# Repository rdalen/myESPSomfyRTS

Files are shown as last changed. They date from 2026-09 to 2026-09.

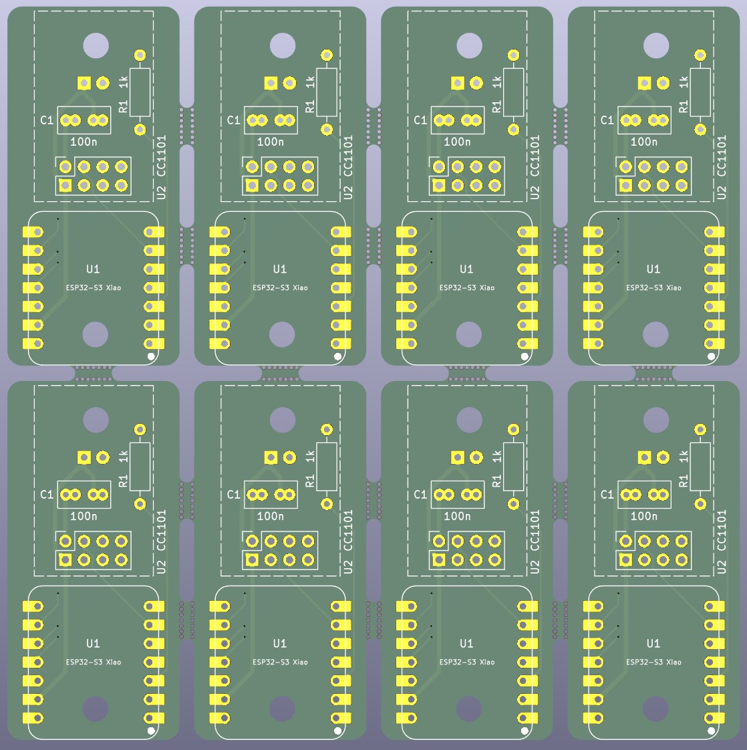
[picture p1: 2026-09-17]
KiCad/ESPSomfyRTS-Panel/ESPSomfyRTS-Panel.jpg

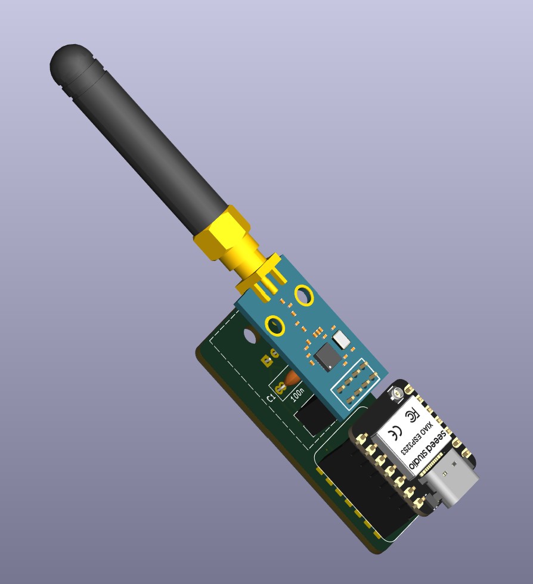
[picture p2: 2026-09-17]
KiCad/ESPSomfyRTS-PcbLayout.jpg

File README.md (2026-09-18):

# myESPSomfyRTS

A DIY Somfy RTS controller for my SunRain Awning/Shade, based on the open-source [ESPSomfyRTS](https://github.com/rstrouse/ESPSomfy-RTS) project.

The controller uses an ESP32 together with a CC1101 433 MHz RF transceiver and integrates with my Home Assistant and Node-RED setup.


<p align="center"><i>Architecture diagram</i></p>

## How It Works

- **Hardware:** ESP32 microcontroller paired with a CC1101 radio transceiver module.
- **Communication:** Connects to my home Wi-Fi network and sends 433 MHz radio signals compatible with the Somfy RTS (Radio Technology Somfy) protocol.
- **Local Operation:** ESPSomfyRTS provides a built-in web interface for controlling the shade directly from a phone or computer.
- **Smart Home Integration:** The controller integrates with Home Assistant and Node-RED for automation and monitoring.
- **Position Tracking:** Tracks the shade position independently of the physical Somfy remote.

For the firmware, general wiring information and ESPSomfyRTS documentation, see the official [ESPSomfyRTS project](https://github.com/rstrouse/ESPSomfy-RTS).

An instruction video is available on [YouTube](https://www.youtube.com/watch?v=1acVJ0xWJgs).

---

## Repository Contents

This repository contains the files specific to my implementation:

- 📁 **[KiCad](./KiCad)** — Schematic and PCB design files
- 📁 **[nodeRed](./nodeRed)** — Node-RED flows used for control, monitoring and automation

The ESP32 firmware itself is based on the [ESPSomfyRTS](https://github.com/rstrouse/ESPSomfy-RTS) project.

---

## CC1101 433 MHz RF Transceiver

CC1101 RF transceiver

E07-M1101D-SMA module

My version of the CC1101-based module (E07-M1101D-SMA) exposes only a single GDO line, while ESPSomfyRTS is often configured with separate RX and TX signal pins.

By assigning both RX and TX to the same GPIO, ESPSomfyRTS can use the single GDO line for both receiving and transmitting.

The GPIO configuration with the Seeed Studio XIAO ESP32-S3 is:

- **RX Pin = GPIO3**
- **TX Pin = GPIO3** ← same GPIO as RX

### ESP32-S3 XIAO

Pin connections between the CC1101 module and the XIAO ESP32-S3:

XIAO ESP32-S3 pinout

| CC1101 Pin | Description | ESP Signal | ESP Pin |
| --- | --- | --- | --- |
| 1 | GND | GND | 13 |
| 2 | VCC | 3V3 | 12 |
| 3 | GDO0 - RX/TX | GPIO 03 | 3 |
| 4 | CSN | GPIO 06 | 6 |
| 5 | SCK | GPIO 07 | 9 |
| 6 | MOSI | GPIO 09 | 11 |
| 7 | MISO | GPIO 08 | 10 |
| 8 | Not connected | | |

Here is the corresponding ESPSomfyRTS radio configuration:

ESPSomfyRTS radio configuration

---

## Schematic & PCB

I designed a small custom PCB for the controller.

The complete KiCad project is available in the **[KiCad](./KiCad)** folder.

PCB

ESPSomfyRTS PCB layout



PCB



PCB

Before ordering, I panelized the PCB design so I have several boards available for experimenting with and sharing.



---

## Enclosure

Finally, I "Boxified" an enclosure for the controller using my [Boxify Parametric Electronics Enclosure Framework](https://cad.onshape.com/documents/2429cd535c2c818681c446f4/w/762b6c313c33766c159c34b3/e/4a0a0d23bcb24ef244694428).

See also my [Boxify Instructable](https://www.instructables.com/-Boxify-a-Parametric-Electronics-Enclosure-Framewo).

The enclosure was then 3D printed.

3D printed enclosure

Enclosure

---

## Controlling the SunRain Shade

The Somfy motor does not provide a motor-running feedback signal.

I therefore derive the motor-running state from a HomeWizard Energy Socket. The motor uses approximately 200 W while running, making it possible to detect whether the motor is active.



For controlling and monitoring the shade I created a Node-RED dashboard.

The complete Node-RED flow is available in the **[nodeRed](./nodeRed)** folder.

The dashboard allows me to:

- control the shade
- monitor whether the motor is responding
- track the shade position
- detect when the motor is running
- receive a warning when rain is predicted within 30 minutes

Node-RED dashboard

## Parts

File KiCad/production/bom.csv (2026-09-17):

Designator | Footprint | Quantity | Value | LCSC Part #
C1_8, C1_7, C1_6, C1_5, C1_4, C1_3, C1_2, C1 | C-Common-THT-P5.08mm | 8 | 100n
D1_8, D1_7, D1_6, D1_5, D1_4, D1_3, D1_2, D1 | LED-D3.0mm | 8 | LED
LOGO1_8, LOGO1_7, LOGO1_6, LOGO1_5, LOGO1_4, LOGO1_3, LOGO1_2, LOGO1 | LOGO-RvD-inverted-small | 8 | Logo-RvD
LOGO2_8, LOGO2_7, LOGO2_6, LOGO2_5, LOGO2_4, LOGO2_3, LOGO2_2, LOGO2 | LOGO-TechDen-inverted | 8 | Logo-TechDen
R1_8, R1_7, R1_6, R1_5, R1_4, R1_3, R1_2, R1 | R-Common-THT-P10.16mm | 8 | 1k
U1_8, U1_7, U1_6, U1_5, U1_4, U1_3, U1_2, U1 | MOD-ESP32-S3-XIAO-DIP | 8 | ESP32-S3 Xiao
U2_8, U2_7, U2_6, U2_5, U2_4, U2_3, U2_2, U2 | MOD-CC1101 | 8 | CC1101

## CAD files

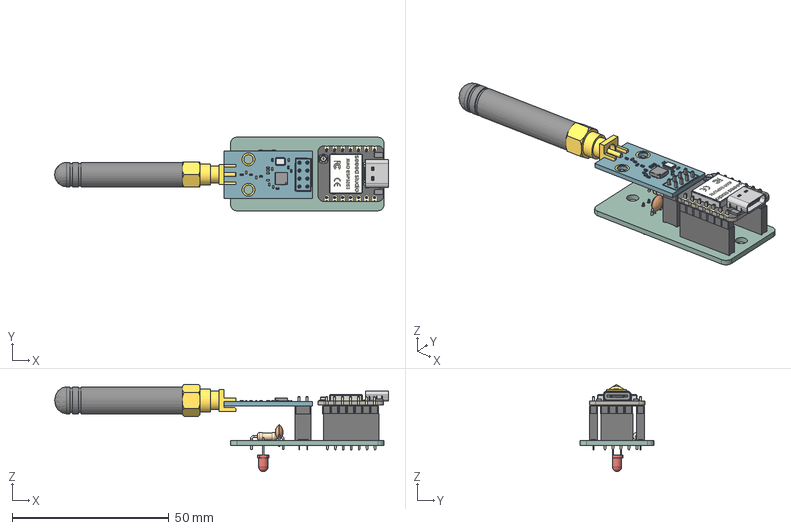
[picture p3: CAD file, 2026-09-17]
KiCad/ESPSomfy RTS.step
106.6 x 23.5 x 27.8 mm
R-Common-THT-P10.16mm
PinHeader_1x07_P2.54mm_Vertical x 2
BOSS-EXTRUDE14_8_
BOSS-EXTRUDE7_4_
BOSS-EXTRUDE7_3_
BOSS-EXTRUDE14_4_
BOSS-EXTRUDE14_2_
BOSS-EXTRUDE14_11_
BOSS-EXTRUDE7_7_
BOSS-EXTRUDE14_9_
BOSS-EXTRUDE14_3_
BOSS-EXTRUDE14_7_
MIRROR2
BOSS-EXTRUDE14_5_
BOSS-EXTRUDE14_12_
BOSS-EXTRUDE7_8_
BOSS-EXTRUDE7_1_
BOSS-EXTRUDE14_10_
BOSS-EXTRUDE7_9_
BOSS-EXTRUDE14_6_
BOSS-EXTRUDE14_1_
BOSS-EXTRUDE7_6_
BOSS-EXTRUDE7_2_
CUT-EXTRUDE5
BOSS-EXTRUDE7_5_
Shield
Pins x 2
U.FL-R-SMT-1_10_ v1
PinSocket_1x07_P2.54mm_Vertical x 2
C-Common-THT-P5.08mm
bits (16)
bits (16)001
bits (16)002
bits (15)
bits (15)001
bits (15)002
bits (14)
bits (14)001
bits (14)002
bits (13)
bits (13)001
bits (13)002
bits (12)
bits (12)001
bits (12)002
bits (11)
bits (11)001
bits (11)002
bits (10)
bits (10)001
bits (10)002
bits (9)
bits (9)001
bits (9)002
bits (8)
bits (8)001
bits (8)002
bits (7)
bits (7)001
bits (7)002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

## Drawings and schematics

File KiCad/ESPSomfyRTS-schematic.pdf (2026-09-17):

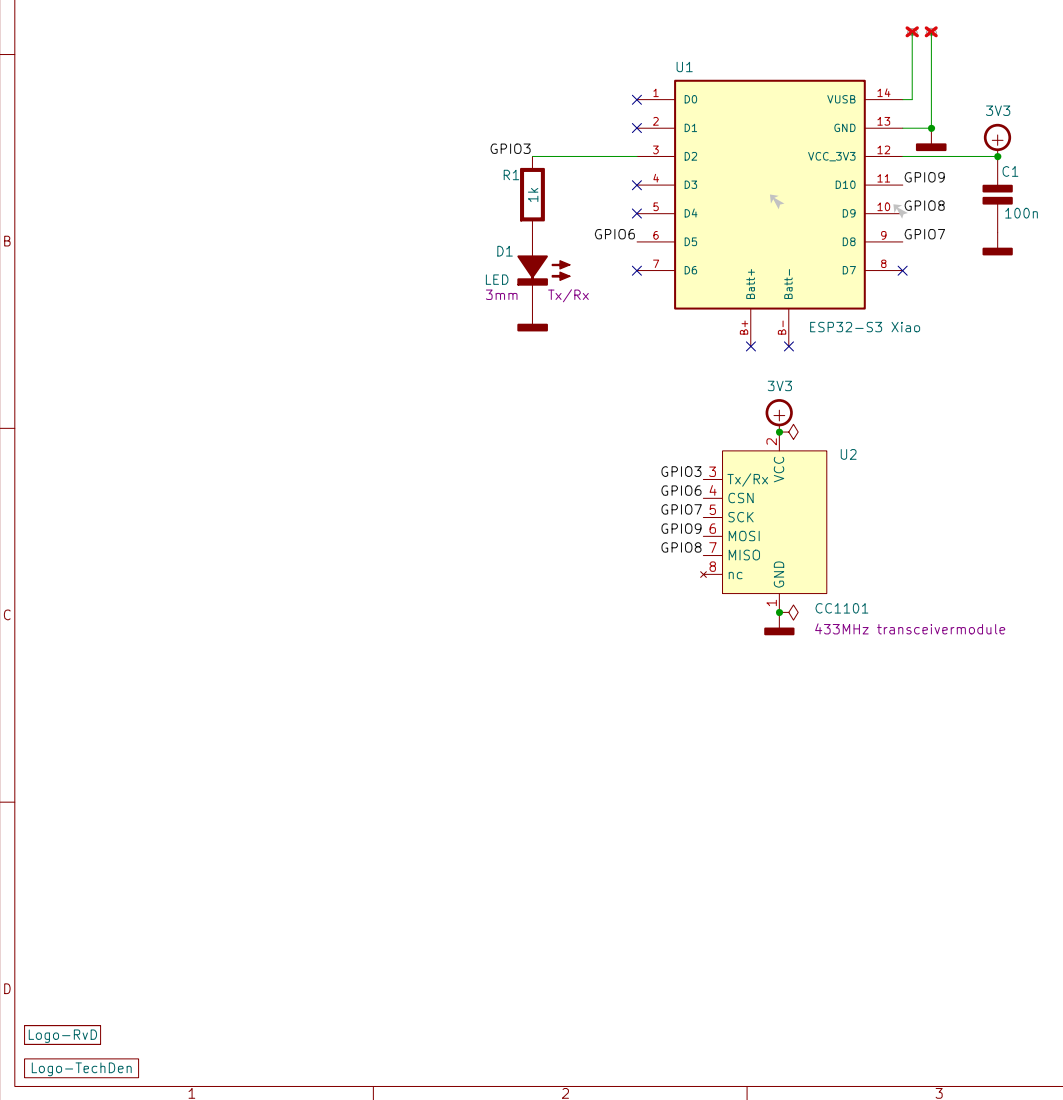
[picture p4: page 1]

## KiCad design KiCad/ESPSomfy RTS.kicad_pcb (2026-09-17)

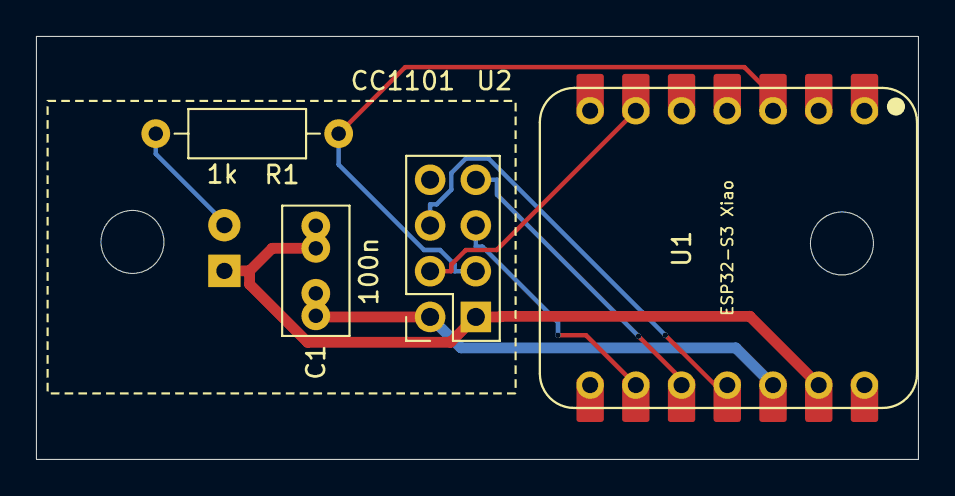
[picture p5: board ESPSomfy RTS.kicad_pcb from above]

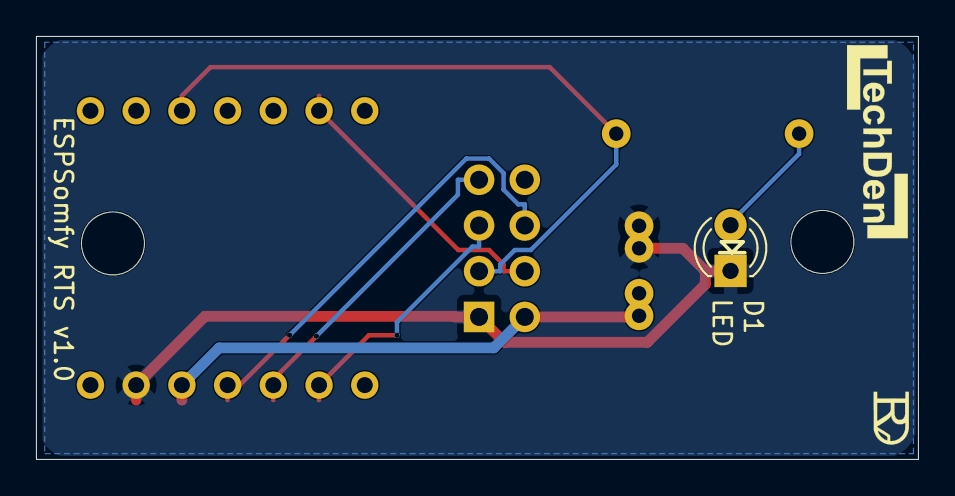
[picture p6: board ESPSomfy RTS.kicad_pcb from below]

Board: 2 copper layers, 49.0 x 23.5 mm, 7 parts (3 on the bottom side), 8 nets.

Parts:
C1: 100n; C-Common-THT-P5.08mm
D1: LED; LED-D3.0mm
Logo1: Logo-RvD; LOGO-RvD-inverted-small
Logo2: Logo-TechDen; LOGO-TechDen-inverted
R1: 1k; R-Common-THT-P10.16mm
U1: ESP32-S3 Xiao; MOD-ESP32-S3-XIAO-DIP
U2: CC1101; MOD-CC1101

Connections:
3V3: C1.1 (+), U1.12 (VCC_3V3), U2.2 (VCC)
/GPIO3: R1.1 (+), U1.3 (D2), U2.3 (Tx/Rx)
/GPIO6: U1.6 (D5), U2.4 (CSN)
/GPIO7: U1.9 (D8), U2.5 (SCK)
/GPIO8: U1.10 (D9), U2.7 (MISO)
/GPIO9: U1.11 (D10), U2.6 (MOSI)
unnamed: D1.2 (A+), R1.2 (-)
U-GND: C1.2 (-), D1.1 (K-), U1.13 (GND), U2.1 (GND)

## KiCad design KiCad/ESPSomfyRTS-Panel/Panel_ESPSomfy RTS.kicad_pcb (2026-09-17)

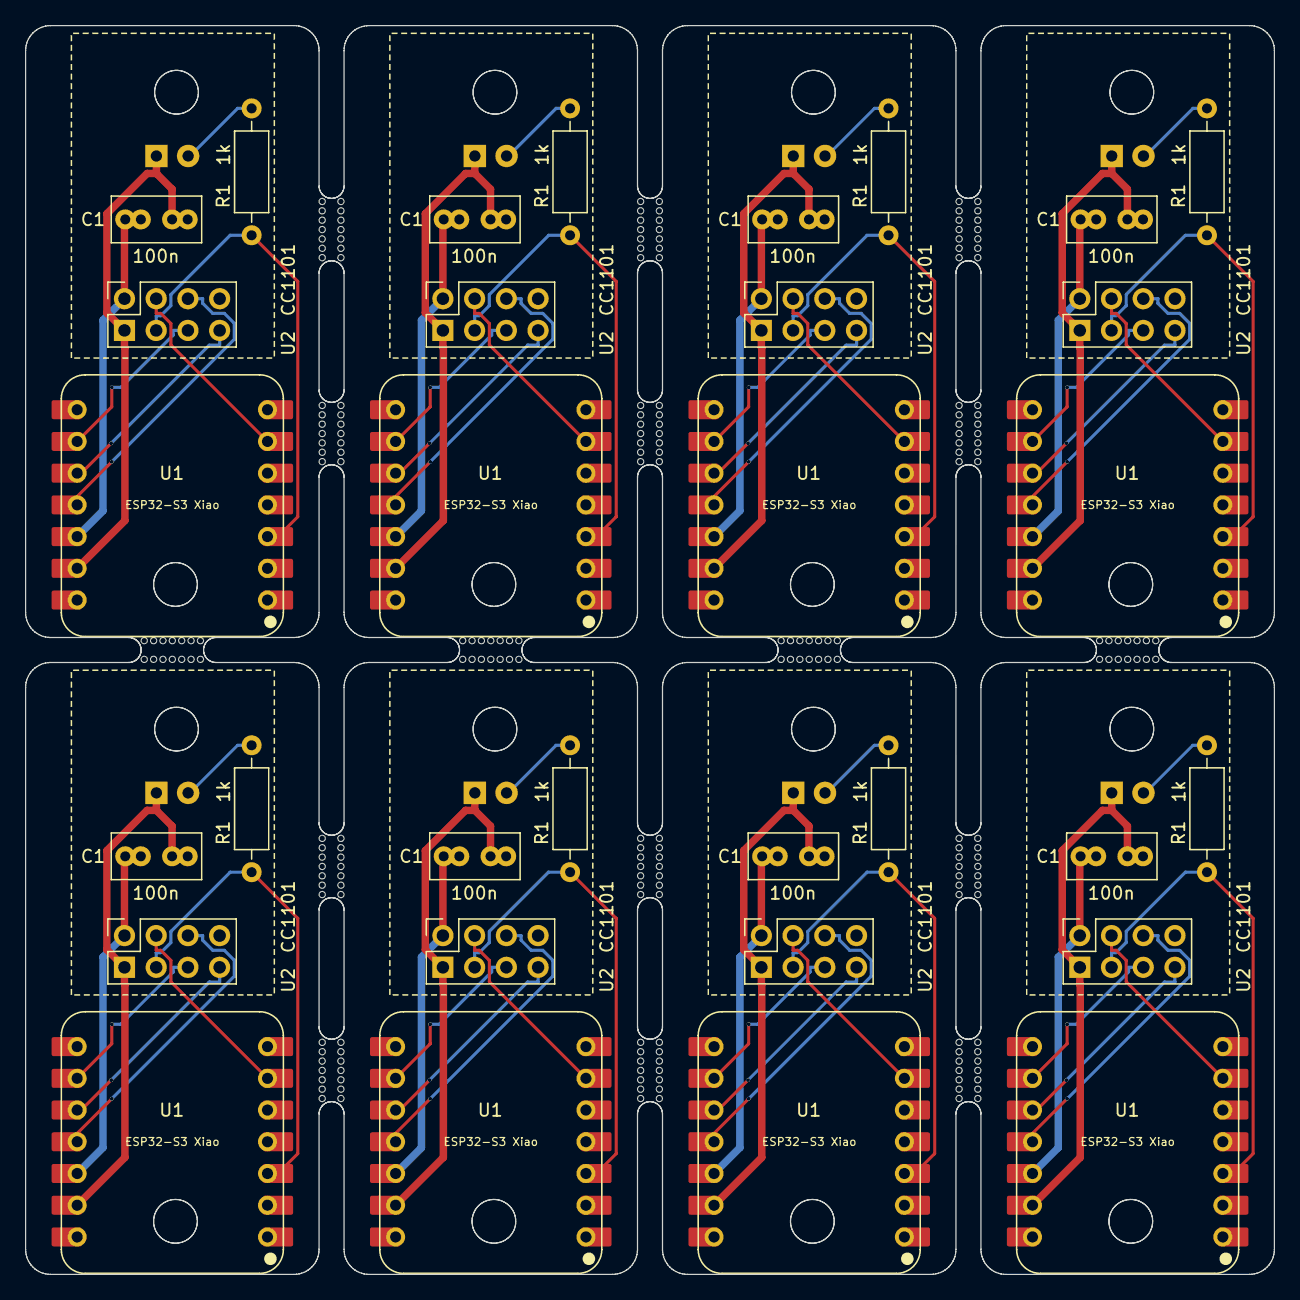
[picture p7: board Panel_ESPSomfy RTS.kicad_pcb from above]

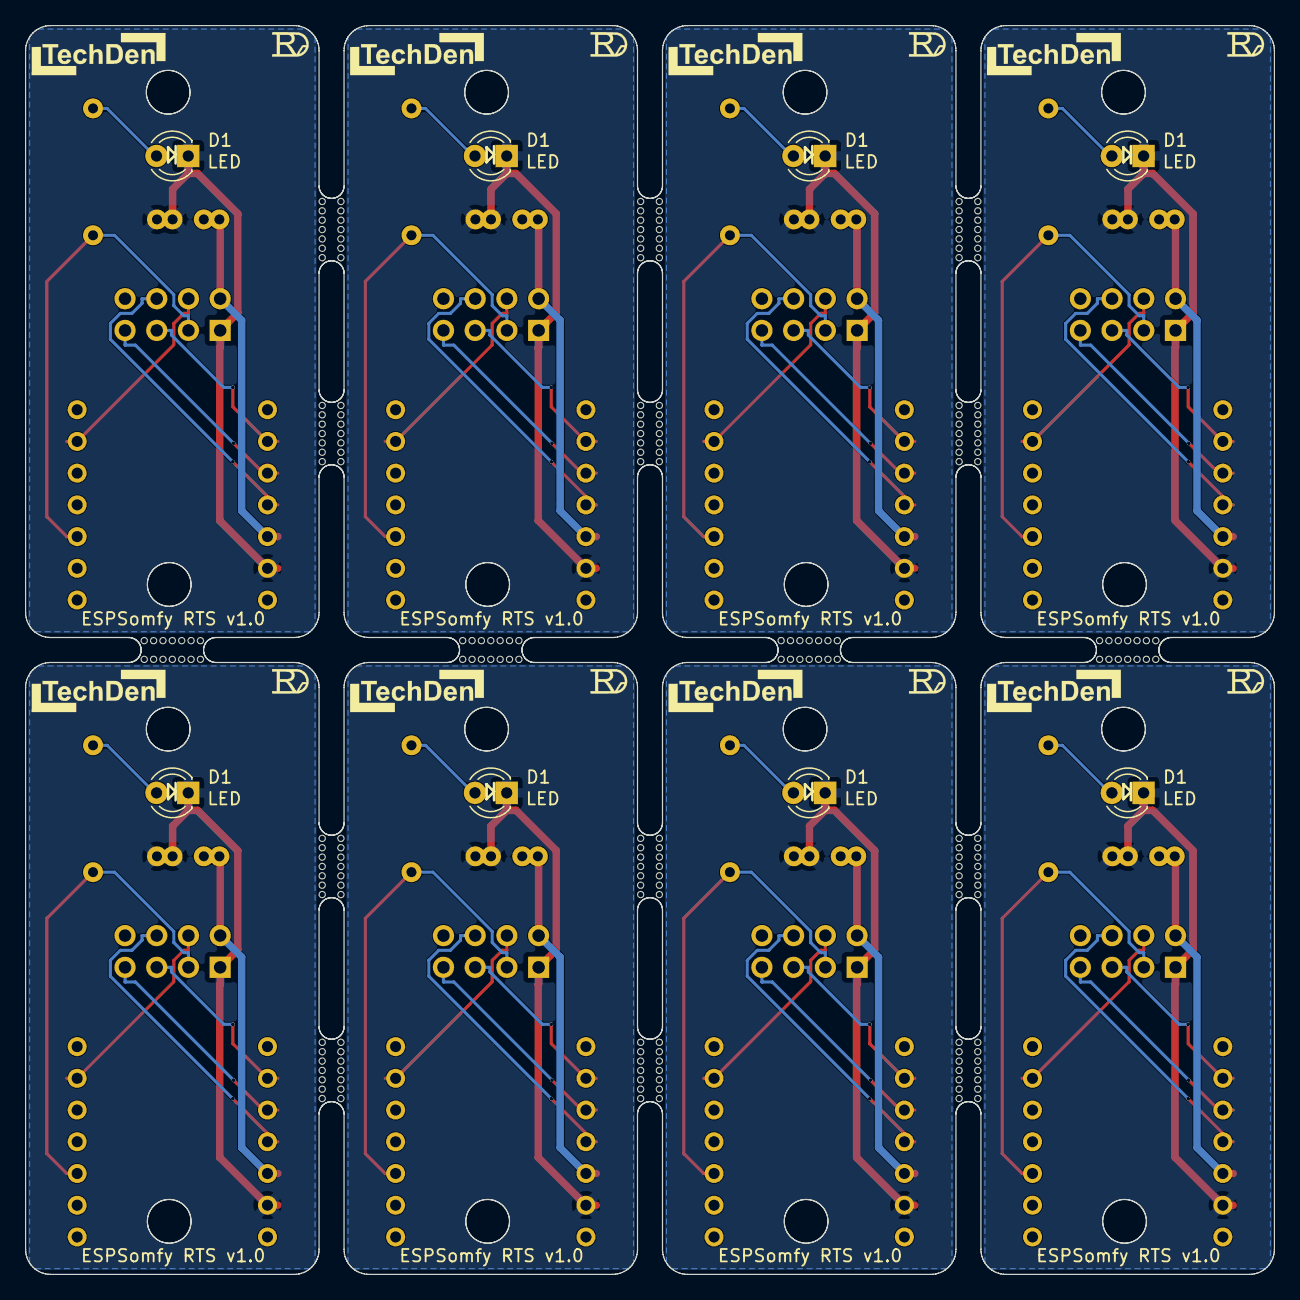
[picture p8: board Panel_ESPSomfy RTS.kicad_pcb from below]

Board: 2 copper layers, 100.0 x 100.0 mm, 280 parts (24 on the bottom side), 64 nets.

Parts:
C1, C1#2, C1#3, C1#4, C1#5, C1#6, C1#7, C1#8: 100n; C-Common-THT-P5.08mm
D1, D1#2, D1#3, D1#4, D1#5, D1#6, D1#7, D1#8: LED; LED-D3.0mm
KiKit_MB_1_2, KiKit_MB_1_3, KiKit_MB_1_4, KiKit_MB_1_5, KiKit_MB_1_6, KiKit_MB_1_7, KiKit_MB_1_8, KiKit_MB_2_2, KiKit_MB_2_3, KiKit_MB_2_4, KiKit_MB_2_5, KiKit_MB_2_6, KiKit_MB_2_7, KiKit_MB_2_8, KiKit_MB_3_2, KiKit_MB_3_3, KiKit_MB_3_4, KiKit_MB_3_5, KiKit_MB_3_6, KiKit_MB_3_7, KiKit_MB_3_8, KiKit_MB_4_2, KiKit_MB_4_3, KiKit_MB_4_4, KiKit_MB_4_5, KiKit_MB_4_6, KiKit_MB_4_7, KiKit_MB_4_8, KiKit_MB_5_2, KiKit_MB_5_3, KiKit_MB_5_4, KiKit_MB_5_5, KiKit_MB_5_6, KiKit_MB_5_7, KiKit_MB_5_8, KiKit_MB_6_2, KiKit_MB_6_3, KiKit_MB_6_4, KiKit_MB_6_5, KiKit_MB_6_6, KiKit_MB_6_7, KiKit_MB_6_8, KiKit_MB_7_2, KiKit_MB_7_3, KiKit_MB_7_4, KiKit_MB_7_5, KiKit_MB_7_6, KiKit_MB_7_7, KiKit_MB_7_8, KiKit_MB_8_2, KiKit_MB_8_3, KiKit_MB_8_4, KiKit_MB_8_5, KiKit_MB_8_6, KiKit_MB_8_7, KiKit_MB_8_8, KiKit_MB_9_2, KiKit_MB_9_3, KiKit_MB_9_4, KiKit_MB_9_5, KiKit_MB_9_6, KiKit_MB_9_7, KiKit_MB_9_8, KiKit_MB_10_2, KiKit_MB_10_3, KiKit_MB_10_4, KiKit_MB_10_5, KiKit_MB_10_6, KiKit_MB_10_7, KiKit_MB_10_8, KiKit_MB_11_2, KiKit_MB_11_3, KiKit_MB_11_4, KiKit_MB_11_5, KiKit_MB_11_6, KiKit_MB_11_7, KiKit_MB_11_8, KiKit_MB_12_2, KiKit_MB_12_3, KiKit_MB_12_4, KiKit_MB_12_5, KiKit_MB_12_6, KiKit_MB_12_7, KiKit_MB_12_8, KiKit_MB_13_2, KiKit_MB_13_3, KiKit_MB_13_4, KiKit_MB_13_5, KiKit_MB_13_6, KiKit_MB_13_7, KiKit_MB_13_8, KiKit_MB_14_2, KiKit_MB_14_3, KiKit_MB_14_4, KiKit_MB_14_5, KiKit_MB_14_6, KiKit_MB_14_7, KiKit_MB_14_8, KiKit_MB_15_2, KiKit_MB_15_3, KiKit_MB_15_4, KiKit_MB_15_5, KiKit_MB_15_6, KiKit_MB_15_7, KiKit_MB_15_8, KiKit_MB_16_2, KiKit_MB_16_3, KiKit_MB_16_4, KiKit_MB_16_5, KiKit_MB_16_6, KiKit_MB_16_7, KiKit_MB_16_8, KiKit_MB_17_2, KiKit_MB_17_3, KiKit_MB_17_4, KiKit_MB_17_5, KiKit_MB_17_6, KiKit_MB_17_7, KiKit_MB_17_8, KiKit_MB_18_2, KiKit_MB_18_3, KiKit_MB_18_4, KiKit_MB_18_5, KiKit_MB_18_6, KiKit_MB_18_7, KiKit_MB_18_8, KiKit_MB_19_2, KiKit_MB_19_3, KiKit_MB_19_4, KiKit_MB_19_5, KiKit_MB_19_6, KiKit_MB_19_7, KiKit_MB_19_8, KiKit_MB_20_2, KiKit_MB_20_3, KiKit_MB_20_4, KiKit_MB_20_5, KiKit_MB_20_6, KiKit_MB_20_7, KiKit_MB_20_8, KiKit_MB_21_2, KiKit_MB_21_3, KiKit_MB_21_4, KiKit_MB_21_5, KiKit_MB_21_6, KiKit_MB_21_7, KiKit_MB_21_8, KiKit_MB_22_2, KiKit_MB_22_3, KiKit_MB_22_4, KiKit_MB_22_5, KiKit_MB_22_6, KiKit_MB_22_7, KiKit_MB_22_8, KiKit_MB_23_2, KiKit_MB_23_3, KiKit_MB_23_4, KiKit_MB_23_5, KiKit_MB_23_6, KiKit_MB_23_7, KiKit_MB_23_8, KiKit_MB_24_2, KiKit_MB_24_3, KiKit_MB_24_4, KiKit_MB_24_5, KiKit_MB_24_6, KiKit_MB_24_7, KiKit_MB_24_8, KiKit_MB_25_2, KiKit_MB_25_3, KiKit_MB_25_4, KiKit_MB_25_5, KiKit_MB_25_6, KiKit_MB_25_7, KiKit_MB_25_8, KiKit_MB_26_2, KiKit_MB_26_3, KiKit_MB_26_4, KiKit_MB_26_5, KiKit_MB_26_6, KiKit_MB_26_7, KiKit_MB_26_8, KiKit_MB_27_2, KiKit_MB_27_3, KiKit_MB_27_4, KiKit_MB_27_5, KiKit_MB_27_6, KiKit_MB_27_7, KiKit_MB_27_8, KiKit_MB_28_2, KiKit_MB_28_3, KiKit_MB_28_4, KiKit_MB_28_5, KiKit_MB_28_6, KiKit_MB_28_7, KiKit_MB_28_8, KiKit_MB_29_2, KiKit_MB_29_3, KiKit_MB_29_4, KiKit_MB_29_5, KiKit_MB_29_6, KiKit_MB_29_7, KiKit_MB_29_8, KiKit_MB_30_2, KiKit_MB_30_3, KiKit_MB_30_4, KiKit_MB_30_5, KiKit_MB_30_6, KiKit_MB_30_7, KiKit_MB_30_8, KiKit_MB_31_2, KiKit_MB_31_3, KiKit_MB_31_4, KiKit_MB_31_5, KiKit_MB_31_6, KiKit_MB_31_7, KiKit_MB_31_8, KiKit_MB_32_2, KiKit_MB_32_3, KiKit_MB_32_4, KiKit_MB_32_5, KiKit_MB_32_6, KiKit_MB_32_7, KiKit_MB_32_8: NPTH
Logo1, Logo1#2, Logo1#3, Logo1#4, Logo1#5, Logo1#6, Logo1#7, Logo1#8: Logo-RvD; LOGO-RvD-inverted-small
Logo2, Logo2#2, Logo2#3, Logo2#4, Logo2#5, Logo2#6, Logo2#7, Logo2#8: Logo-TechDen; LOGO-TechDen-inverted
R1, R1#2, R1#3, R1#4, R1#5, R1#6, R1#7, R1#8: 1k; R-Common-THT-P10.16mm
U1, U1#2, U1#3, U1#4, U1#5, U1#6, U1#7, U1#8: ESP32-S3 Xiao; MOD-ESP32-S3-XIAO-DIP
U2, U2#2, U2#3, U2#4, U2#5, U2#6, U2#7, U2#8: CC1101; MOD-CC1101

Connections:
Board_0-3V3: C1.1 (+), U1#5.12 (VCC_3V3), U2#7.2 (VCC)
Board_0-/GPIO3: R1#3.1 (+), U1#5.3 (D2), U2#7.3 (Tx/Rx)
Board_0-/GPIO6: U1#5.6 (D5), U2#7.4 (CSN)
Board_0-/GPIO7: U1#5.9 (D8), U2#7.5 (SCK)
Board_0-/GPIO8: U1#5.10 (D9), U2#7.7 (MISO)
Board_0-/GPIO9: U1#5.11 (D10), U2#7.6 (MOSI)
Board_0-Net-(D1-A+): D1.2 (A+), R1#3.2 (-)
Board_0-U-GND: C1.2 (-), D1.1 (K-), U1#5.13 (GND), U2#7.1 (GND)
Board_1-3V3: C1#4.1 (+), U1#4.12 (VCC_3V3), U2#5.2 (VCC)
Board_1-/GPIO3: R1#5.1 (+), U1#4.3 (D2), U2#5.3 (Tx/Rx)
Board_1-/GPIO6: U1#4.6 (D5), U2#5.4 (CSN)
Board_1-/GPIO7: U1#4.9 (D8), U2#5.5 (SCK)
Board_1-/GPIO8: U1#4.10 (D9), U2#5.7 (MISO)
Board_1-/GPIO9: U1#4.11 (D10), U2#5.6 (MOSI)
Board_1-Net-(D1-A+): D1#5.2 (A+), R1#5.2 (-)
Board_1-U-GND: C1#4.2 (-), D1#5.1 (K-), U1#4.13 (GND), U2#5.1 (GND)
Board_2-3V3: C1#7.1 (+), U1#3.12 (VCC_3V3), U2#4.2 (VCC)
Board_2-/GPIO3: R1#2.1 (+), U1#3.3 (D2), U2#4.3 (Tx/Rx)
Board_2-/GPIO6: U1#3.6 (D5), U2#4.4 (CSN)
Board_2-/GPIO7: U1#3.9 (D8), U2#4.5 (SCK)
Board_2-/GPIO8: U1#3.10 (D9), U2#4.7 (MISO)
Board_2-/GPIO9: U1#3.11 (D10), U2#4.6 (MOSI)
Board_2-Net-(D1-A+): D1#3.2 (A+), R1#2.2 (-)
Board_2-U-GND: C1#7.2 (-), D1#3.1 (K-), U1#3.13 (GND), U2#4.1 (GND)
Board_3-3V3: C1#8.1 (+), U1#6.12 (VCC_3V3), U2#6.2 (VCC)
Board_3-/GPIO3: R1#7.1 (+), U1#6.3 (D2), U2#6.3 (Tx/Rx)
Board_3-/GPIO6: U1#6.6 (D5), U2#6.4 (CSN)
Board_3-/GPIO7: U1#6.9 (D8), U2#6.5 (SCK)
Board_3-/GPIO8: U1#6.10 (D9), U2#6.7 (MISO)
Board_3-/GPIO9: U1#6.11 (D10), U2#6.6 (MOSI)
Board_3-Net-(D1-A+): D1#4.2 (A+), R1#7.2 (-)
Board_3-U-GND: C1#8.2 (-), D1#4.1 (K-), U1#6.13 (GND), U2#6.1 (GND)
Board_4-3V3: C1#5.1 (+), U1#2.12 (VCC_3V3), U2.2 (VCC)
Board_4-/GPIO3: R1.1 (+), U1#2.3 (D2), U2.3 (Tx/Rx)
Board_4-/GPIO6: U1#2.6 (D5), U2.4 (CSN)
Board_4-/GPIO7: U1#2.9 (D8), U2.5 (SCK)
Board_4-/GPIO8: U1#2.10 (D9), U2.7 (MISO)
Board_4-/GPIO9: U1#2.11 (D10), U2.6 (MOSI)
Board_4-Net-(D1-A+): D1#7.2 (A+), R1.2 (-)
Board_4-U-GND: C1#5.2 (-), D1#7.1 (K-), U1#2.13 (GND), U2.1 (GND)
Board_5-3V3: C1#2.1 (+), U1#8.12 (VCC_3V3), U2#3.2 (VCC)
Board_5-/GPIO3: R1#8.1 (+), U1#8.3 (D2), U2#3.3 (Tx/Rx)
Board_5-/GPIO6: U1#8.6 (D5), U2#3.4 (CSN)
Board_5-/GPIO7: U1#8.9 (D8), U2#3.5 (SCK)
Board_5-/GPIO8: U1#8.10 (D9), U2#3.7 (MISO)
Board_5-/GPIO9: U1#8.11 (D10), U2#3.6 (MOSI)
Board_5-Net-(D1-A+): D1#8.2 (A+), R1#8.2 (-)
Board_5-U-GND: C1#2.2 (-), D1#8.1 (K-), U1#8.13 (GND), U2#3.1 (GND)
Board_6-3V3: C1#6.1 (+), U1.12 (VCC_3V3), U2#2.2 (VCC)
Board_6-/GPIO3: R1#6.1 (+), U1.3 (D2), U2#2.3 (Tx/Rx)
Board_6-/GPIO6: U1.6 (D5), U2#2.4 (CSN)
Board_6-/GPIO7: U1.9 (D8), U2#2.5 (SCK)
Board_6-/GPIO8: U1.10 (D9), U2#2.7 (MISO)
Board_6-/GPIO9: U1.11 (D10), U2#2.6 (MOSI)
Board_6-Net-(D1-A+): D1#6.2 (A+), R1#6.2 (-)
Board_6-U-GND: C1#6.2 (-), D1#6.1 (K-), U1.13 (GND), U2#2.1 (GND)
Board_7-3V3: C1#3.1 (+), U1#7.12 (VCC_3V3), U2#8.2 (VCC)
Board_7-/GPIO3: R1#4.1 (+), U1#7.3 (D2), U2#8.3 (Tx/Rx)
Board_7-/GPIO6: U1#7.6 (D5), U2#8.4 (CSN)
Board_7-/GPIO7: U1#7.9 (D8), U2#8.5 (SCK)
Board_7-/GPIO8: U1#7.10 (D9), U2#8.7 (MISO)
Board_7-/GPIO9: U1#7.11 (D10), U2#8.6 (MOSI)
Board_7-Net-(D1-A+): D1#2.2 (A+), R1#4.2 (-)
Board_7-U-GND: C1#3.2 (-), D1#2.1 (K-), U1#7.13 (GND), U2#8.1 (GND)

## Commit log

2026-09-17 Update README with PCB design panellization note
    Added a note about panellizing PCB design for experimentation or distribution.
2026-09-18 Adjust image sizes and add new PCB images
    Updated image sizes and added new images in the README.
2026-10-24 Include STL files for 3D printed enclosure
    Added information about STL files for 3D printing the enclosure.
